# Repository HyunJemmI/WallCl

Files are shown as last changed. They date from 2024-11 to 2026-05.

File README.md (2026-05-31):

# WallCl

WallCl은 2020 SRC/IRC 지능형 창작 로봇 대회에서 제작한 벽면 등반 로봇입니다. 건물 붕괴와 같은 재난 환경에서 벽에 붙어 이동하며 구조 물품을 전달하는 상황을 목표로 설계했습니다. 게코 도마뱀의 벽면 이동 방식에서 아이디어를 얻어, 전자석으로 벽면에 고정하고 서보모터로 다리를 움직이는 구조를 구현했습니다.

프로젝트 정리 페이지: https://hyunjem.notion.site/wallcl

## 프로젝트 개요

로봇은 다리와 연결된 서보모터를 일정 각도 순서로 회전시켜 전진과 좌우 방향 전환을 수행합니다. 이동 중에는 전자석을 이용해 벽면에 부착된 상태를 유지하고, 초음파 센서로 전방 장애물을 감지해 이동 방향을 판단하도록 설계했습니다.

기구 설계는 가벼운 무게와 높은 강도를 동시에 만족하는 데 집중했습니다. 본체와 다리는 SketchUp으로 직접 모델링한 뒤 3D 프린터로 출력했습니다. 본체에는 안정성을 높이기 위해 삼각형 구조를 적용했고, 다리는 종이를 T자 형태로 접었을 때 강성이 높아지는 원리에서 착안해 T자 구조로 설계했습니다.

## 사용 부품

| 구분 | 부품 |
| --- | --- |
| MCU | Arduino Uno (ATmega328) |
| 서보모터 | MG996R |
| 서보 드라이버 | PCA9685 PWM Servo Driver |
| 초음파 센서 | HC-SR04P |
| 전자석 | WF-P30 |
| 전자석 구동 | IRF520 MOSFET |
| 본체/다리 | SketchUp 설계 기반 PLA 3D 프린팅 구조물 |
| MCU 전원 | 9V 배터리 2개 병렬 연결 |
| 서보/센서 전원 | 5V Linear Regulator 출력 |
| 전자석 전원 | 외부 21V 전원 |

## 핀맵

| 구분 | 연결 |
| --- | --- |
| PCA9685 SDA/SCL | Arduino Uno I2C |
| 전자석 0 | D3 |
| 전자석 1 | D4 |
| 전자석 2 | D5 |
| 서보 채널 0 | PCA9685 0번 채널 |
| 서보 채널 1 | PCA9685 1번 채널 |
| 서보 채널 2 | PCA9685 2번 채널 |

초음파 센서는 전방 장애물 감지용으로 설계에 포함되며, 다리 이동 반경을 고려해 약 2cm 여유 거리를 두고 장애물을 판단합니다.

## 시스템 동작 흐름

1. Arduino가 PCA9685 서보 드라이버를 50Hz로 초기화합니다.
2. D3, D4, D5 전자석 제어 핀을 출력으로 설정합니다.
3. 기본 상태에서 모든 전자석을 켜 벽면 고정력을 유지합니다.
4. Serial 명령을 입력받아 이동 방향을 선택합니다.
5. 명령 `0`은 전진, `1`은 좌회전, `2`는 우회전에 대응합니다.
6. 선택된 방향에 따라 두 개의 서보 채널을 한 쌍으로 움직입니다.
7. 사전에 계산한 각도 시퀀스를 PWM 펄스로 변환해 서보모터에 전달합니다.
8. 동작이 끝나면 두 서보를 기준 위치로 복귀시킵니다.

## 주요 기능

- 전자석 기반 벽면 부착 유지
- PCA9685 기반 다중 서보모터 제어
- Serial 명령 기반 전진/좌회전/우회전 동작
- 각도 시퀀스를 이용한 다리 보행 패턴 구현
- 초음파 센서 기반 전방 장애물 감지 설계
- SketchUp 기반 3D 모델링 및 PLA 출력
- T자형 다리 구조를 통한 경량 강성 확보

## 코드 구조

```text
WallCl/
├── README.md
├── model/
│   ├── frame.stl   # 본체 프레임 3D 모델
│   └── legs.stl    # 다리 구조 3D 모델
└── src/
    └── code.ino    # Arduino 서보/전자석 제어 코드
```

## 실행 방법

1. Arduino IDE에서 `src/code.ino`를 엽니다.
2. `Adafruit PWM Servo Driver Library`를 설치합니다.
3. Arduino Uno와 PCA9685, 전자석 제어 회로를 핀맵에 맞게 연결합니다.
4. 보드와 포트를 선택한 뒤 업로드합니다.
5. Serial Monitor 또는 외부 제어 프로그램에서 명령을 전송합니다.

| 명령 | 동작 |
| --- | --- |
| `0` | 전진 |
| `1` | 좌회전 |
| `2` | 우회전 |

## 시연 결과 또는 기대 동작

- 전자석이 활성화되어 로봇이 벽면에 부착됩니다.
- 명령 `0` 입력 시 서보 채널 0, 1이 전진 보행 패턴으로 움직입니다.
- 명령 `1` 입력 시 서보 채널 2, 0이 좌회전 패턴으로 움직입니다.
- 명령 `2` 입력 시 서보 채널 1, 2가 우회전 패턴으로 움직입니다.
- 보행 동작 후 서보는 기준 위치로 복귀하고 다음 명령을 기다립니다.

## 설계 포인트

- 전자석의 자력이 로봇 무게를 견딜 수 있도록 본체를 경량화했습니다.
- SketchUp으로 본체 프레임과 다리 구조를 직접 설계하고 3D 프린팅했습니다.
- 삼각형 프레임으로 벽면 부착 상태에서 구조 안정성을 높였습니다.
- 다리는 T자 형태로 설계해 낮은 무게로 강성을 확보했습니다.
- 이동 정확도와 1회 이동 거리를 고려해 다리 길이와 전자석 부착 위치를 조정했습니다.
- 서보모터 각도는 로봇 팔 사이 거리와 가동 범위를 계산해 시퀀스로 구성했습니다.

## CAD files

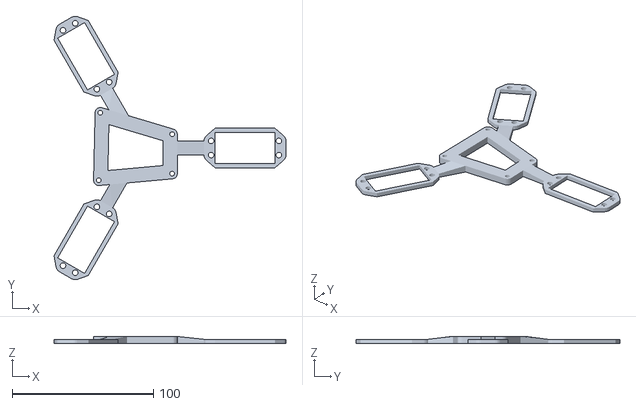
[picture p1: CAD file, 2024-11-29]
model/frame.stl
164.2 x 186.5 x 5.00

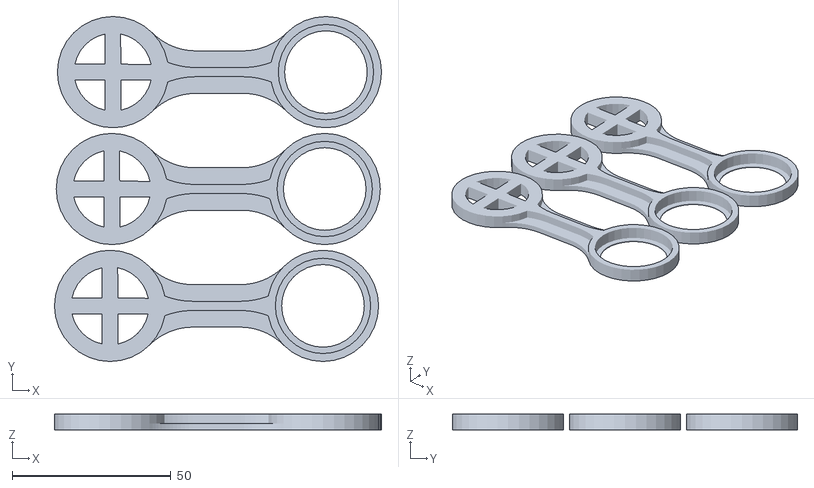
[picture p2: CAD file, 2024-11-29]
model/legs.stl
102.9 x 108.6 x 5.00

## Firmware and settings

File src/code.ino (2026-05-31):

#include <Wire.h>
#include <Adafruit_PWMServoDriver.h>

Adafruit_PWMServoDriver pwm = Adafruit_PWMServoDriver();

const int MAGNET_PINS[] = {3, 4, 5};
const int MAGNET_COUNT = sizeof(MAGNET_PINS) / sizeof(MAGNET_PINS[0]);

const int PWM_FREQUENCY_HZ = 50;
const int PWM_MIN = 150;
const int PWM_MAX = 600;
const int SERVO_RESET_LOW = 225;
const int SERVO_RESET_HIGH = 525;

const int STEP_DELAY_MS = 10;
const int MOTION_SETTLE_DELAY_MS = 5000;

const char COMMAND_FORWARD = '0';
const char COMMAND_LEFT = '1';
const char COMMAND_RIGHT = '2';

struct MotionStep {
  double startA;
  double startB;
  double endA;
  double endB;
  double stepA;
  double stepB;
};

const MotionStep MOTION_STEPS[] = {
  {30.0, 150.0, 9.155, 108.31, -0.1, -0.2},
  {9.155, 108.31, 108.31, 9.155, 0.1, -0.1},
  {108.31, 9.155, 150.0, 30.0, 0.2, 0.1},
};

void setup() {
  Serial.begin(9600);
  pwm.begin();
  pwm.setPWMFreq(PWM_FREQUENCY_HZ);

  for (int i = 0; i < MAGNET_COUNT; i++) {
    pinMode(MAGNET_PINS[i], OUTPUT);
  }
}

void loop() {
  enableAllMagnets();

  if (!Serial.available()) {
    return;
  }

  char command = Serial.read();
  if (command == COMMAND_FORWARD) {
    Serial.print(command);
    act(0, 1);
  } else if (command == COMMAND_LEFT) {
    Serial.print(command);
    act(2, 0);
  } else if (command == COMMAND_RIGHT) {
    Serial.print(command);
    act(1, 2);
  }
}

void enableAllMagnets() {
  for (int i = 0; i < MAGNET_COUNT; i++) {
    digitalWrite(MAGNET_PINS[i], HIGH);
  }
}

void act(int servoA, int servoB) {
  for (int i = 0; i < 3; i++) {
    moveServoPair(servoA, servoB, MOTION_STEPS[i]);
  }

  pwm.setPWM(servoA, 0, SERVO_RESET_LOW);
  pwm.setPWM(servoB, 0, SERVO_RESET_HIGH);
  delay(MOTION_SETTLE_DELAY_MS);
}

void moveServoPair(int servoA, int servoB, MotionStep step) {
  double angleA = step.startA;
  double angleB = step.startB;

  while (isWithinRange(angleA, step.endA, step.stepA) &&
         isWithinRange(angleB, step.endB, step.stepB)) {
    pwm.setPWM(servoA, 0, angleToPulse(angleA));
    pwm.setPWM(servoB, 0, angleToPulse(angleB));

    angleA += step.stepA;
    angleB += step.stepB;
    delay(STEP_DELAY_MS);
  }
}

bool isWithinRange(double value, double endValue, double stepValue) {
  if (stepValue > 0) {
    return value <= endValue;
  }
  return value >= endValue;
}

int angleToPulse(double angle) {
  return constrain(map(angle, 0, 180, PWM_MIN, PWM_MAX), PWM_MIN, PWM_MAX);
}
